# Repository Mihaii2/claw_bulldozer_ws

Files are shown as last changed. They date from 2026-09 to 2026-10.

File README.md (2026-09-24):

# Autonomous Claw Bulldozer ROS 2 Workspace

An autonomous manipulation and earth-moving platform featuring a multi-axis articulating high-torque claw and bucket mechanism, 4WD skid-steer chassis, ESP32 dual-core real-time control, onboard IMU pose tracking, dual camera vision systems, and ROS 2 Jazzy integration.

> 📦 **Hardware Heritage & Lineage Notice:** Core electronics (ESP32 DevKitC, TC1508 H-bridge, GY-BMI160 6-DOF IMU, buck converters) and the baseline micro-ROS architecture were harvested and evolved from the decommissioned [Mihaii2/esp32_flipper_car](https://github.com/Mihaii2/esp32_flipper_car).

<div align="center">
  Autonomous Claw Bulldozer Actuation & Teleoperation Demo<br/>
  <em>Autonomous Claw Bulldozer in action: Synchronized multi-axis lift, bucket articulation, and payload capture.</em>
</div>

<br/>

<div align="center">
  <table>
    <tr>
      <td align="center" width="33%">
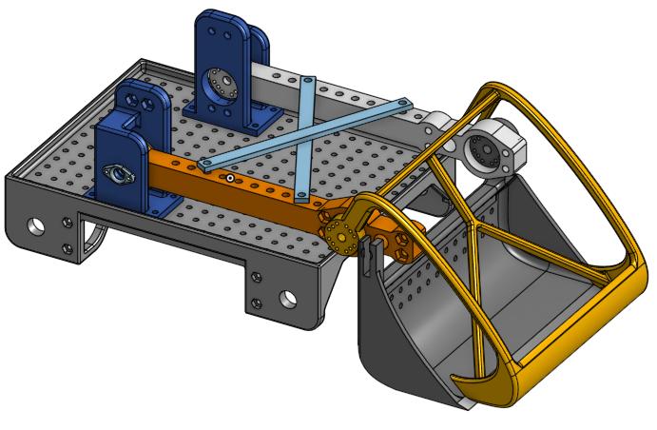
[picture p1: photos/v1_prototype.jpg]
Revision 1: Skinny Skeleton Prototype
        <br/>
        <b>Revision 1: Organic Lattice</b><br/>
        <em>3D round skeleton claw; discarded due to massive support waste and print cost.</em>
      </td>
      <td align="center" width="33%">
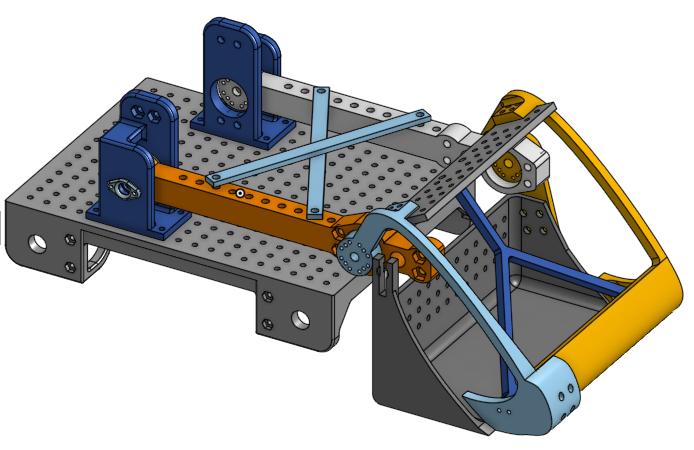
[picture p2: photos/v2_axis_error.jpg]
Revision 2: Off-Axis Pivot
        <br/>
        <b>Revision 2: Split Axis Failure</b><br/>
        <em>Cheaper multi-part claw, but non-concentric pivot axes and horn bolt misalignments failed grip lock.</em>
      </td>
      <td align="center" width="33%">
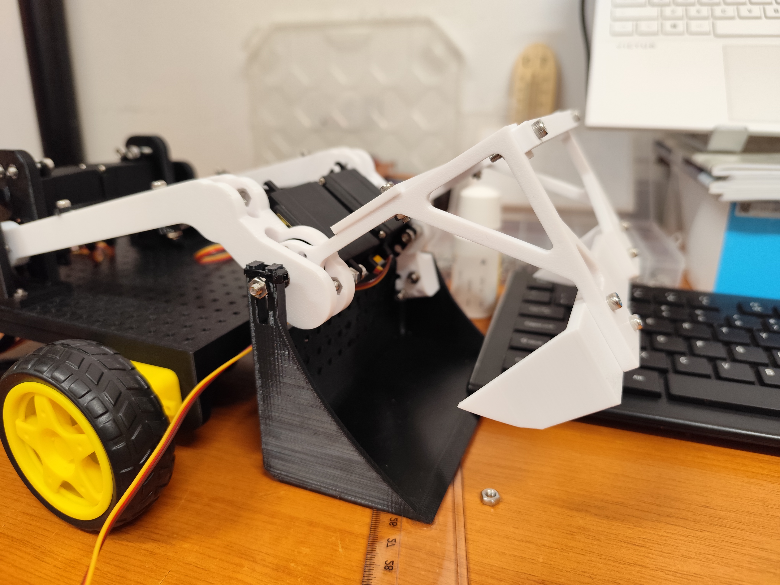
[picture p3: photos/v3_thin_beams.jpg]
Revision 3: Concentric Thin Beams
        <br/>
        <b>Revision 3: Compliant Beams</b><br/>
        <em>Concentric claw/cup axis resolved kinematics, but thin support arms caused excessive structural flex.</em>
      </td>
    </tr>
    <tr>
      <td align="center" width="33%">
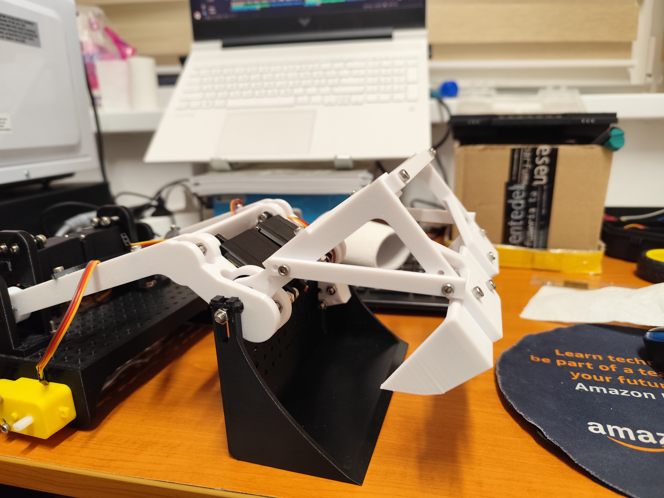
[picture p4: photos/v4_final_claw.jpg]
Revision 4: Rigid Reinforced Claw
        <br/>
        <b>Revision 4: Rigid Production</b><br/>
        <em>Reinforced structural beam geometry; eliminates claw deflection and locks payload into collection cup.</em>
      </td>
      <td align="center" width="33%">
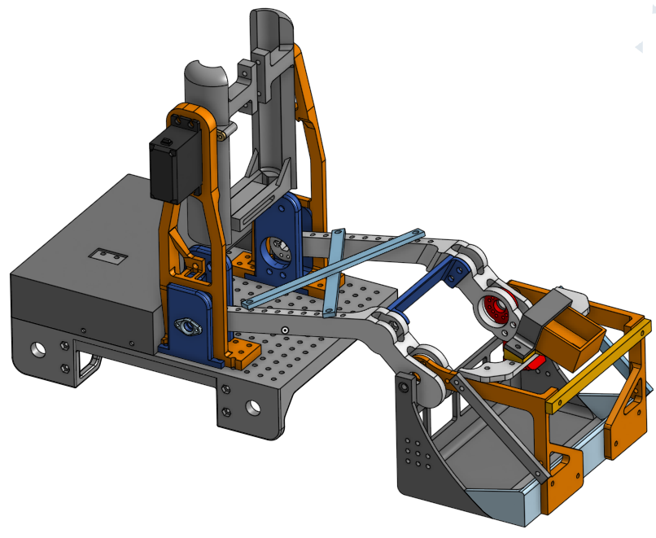
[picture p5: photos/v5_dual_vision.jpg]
Revision 5: Dual Vision & Phone Tilter Rig
        <br/>
        <b>Revision 5: Dual Vision & Enclosure Rig</b><br/>
        <em>Beam-enclosed ESP32-CAM, 5th-servo phone tilter mast, and custom electronics protective cover.</em>
      </td>
      <td align="center" width="33%">
        </td>
    </tr>
  </table>
</div>

> **🛠 Engineering Revision History & CAD Iteration Log:**
> * **v1.0 (Organic Monolithic Claw):** Claw designed as a continuous 3D organic round skeleton. While lightweight on paper, slicer analysis proved it unviable for FDM printing: massive support structures consumed more filament than the part itself, driving print failure rates and material cost excessively high.
> * **v2.0 (Modular Shell & The Pivot Misalignment Post-Mortem):** Redesigned the claw into flat-laying, easily printable structural components, as well as redesigning the chassis goussets to get rid of a lot of waste support plastic. However, rapid CAD prototyping introduced two major mechanical flaws:
>   * **Axial Offset:** The bucket/cup swing axis and the claw rotation axis were placed on disparate coordinate planes rather than a single concentric shaft. The mechanical offset degraded clamping reach, making object acquisition unreliable.
>   * **Horn Geometry Error:** Servo horn mounting hole pitch and bolt clearances were mismeasured, preventing secure mechanical torque transfer without binding.
> * **v3.0 (Concentric Axis & Structural Compliance Investigation):** Redesigned the mounting hub to align the cup and claw along a shared, concentric pivot axis. The mechanical geometry functioned correctly, but the claw extension beams were undersized in thickness. Clamping torque from the MG995 servos flexed the beams outward rather than transferring grip pressure into the target object.
> * **v4.0 (Rigid Structural Reinforcement):** Completely re-engineered the claw support beams with increased cross-sectional area and internal ribbing. Flex is eliminated, permitting high-torque payload capture and retraction directly into the retention cup.
> * **v4.1 (Locomotion Tuning & Track/Wheel Calibration):**
>   * **Wheel Dimensional Scaling:** Replaced oversized 45mm-radius wheel collisions with realistic 20mm-radius (40mm diameter) hubs recessed directly into the chassis axle slots for accurate Gazebo physics and ground clearance.
>   * **Pivot & Scrubbing Firmware Mitigation:** Tuned the differential drive turning profile across all speed gears to supply 100% PWM (255) to the outside wheels and 0% PWM to the inside wheels during turns, breaking lateral static friction without stalling the motors.
>   * **Drivetrain Upgrade Roadmap:** Acquired **all-metal TT 1:90 6V reduction gearboxes** to replace the stock yellow plastic units, delivering substantial low-end torque for heavy earth-moving without risk of gear-tooth shearing.
> * **v5.0 (Perception, High-Current Power & Electronics Shielding — Current Hardware):**
>   * **Initial ESP32-CAM Prototype:** Early tests yielded severe frame-drop bottlenecks, latency, and poor visual fidelity under default configurations.
>   * **Smartphone Mount Pivot:** Designed a dedicated smartphone holder actuated by a 5th MG995 servo on `GPIO 4` to handle primary teleoperation and high-resolution spatial streaming via a mobile device.
>   * **Dual-Camera Convergence & Custom Enclosure:** Subsequent firmware optimizations, clock adjustments, and memory pipeline tuning substantially stabilized ESP32-CAM stream throughput. Attempting to mount the bare board to the pre-existing overhead beam directly above the claw proved mechanically unviable and structurally awkward. Consequently, engineered a custom dedicated 3D-printed plastic enclosure tailored specifically to house the ESP32-CAM and lock rigidly onto the upper beam assembly. The platform now implements a **dual-vision stack**: an actuated smartphone tilter for primary broad-field telemetry and a ruggedized, enclosed ESP32-CAM for direct manipulation monitoring, alongside an upcoming **8×8 Time-of-Flight (ToF)** distance matrix.
>   * **2S2P High-Current Battery Array (Brownout Mitigation):** In the 2-cell configuration, intense multi-joint dynamic actuation (simultaneous 5-servo manipulation alongside aggressive 4WD skid-steer scrubbing) drew more peak current than the pack could sustain. The severe voltage sag triggered brownout resets on the ESP32 logic rail. To resolve this, added two additional 18650 cells wired in parallel (**2S2P topology**). The battery pack maintains nominal **7.4V** while unlocking a massive **20A instantaneous discharge headroom**, ensuring complete electrical stability under full-load operation.
>   * **RF Range Expansion:** Added dedicated 3dBi external dipole antennas to both the main motherboard ESP32 and the secondary ESP32-CAM to prevent telemetry drops and feed degradation across Wi-Fi.
>   * **Electronics Enclosure / Cover:** Designed and printed a custom top-shell protective cover shielding the modular quad-perfboard assembly, buck converters, and wiring harness from earth, debris, and direct mechanical impacts during aggressive digging operations.

---

## 📐 Circuit Schematic

<div align="center">
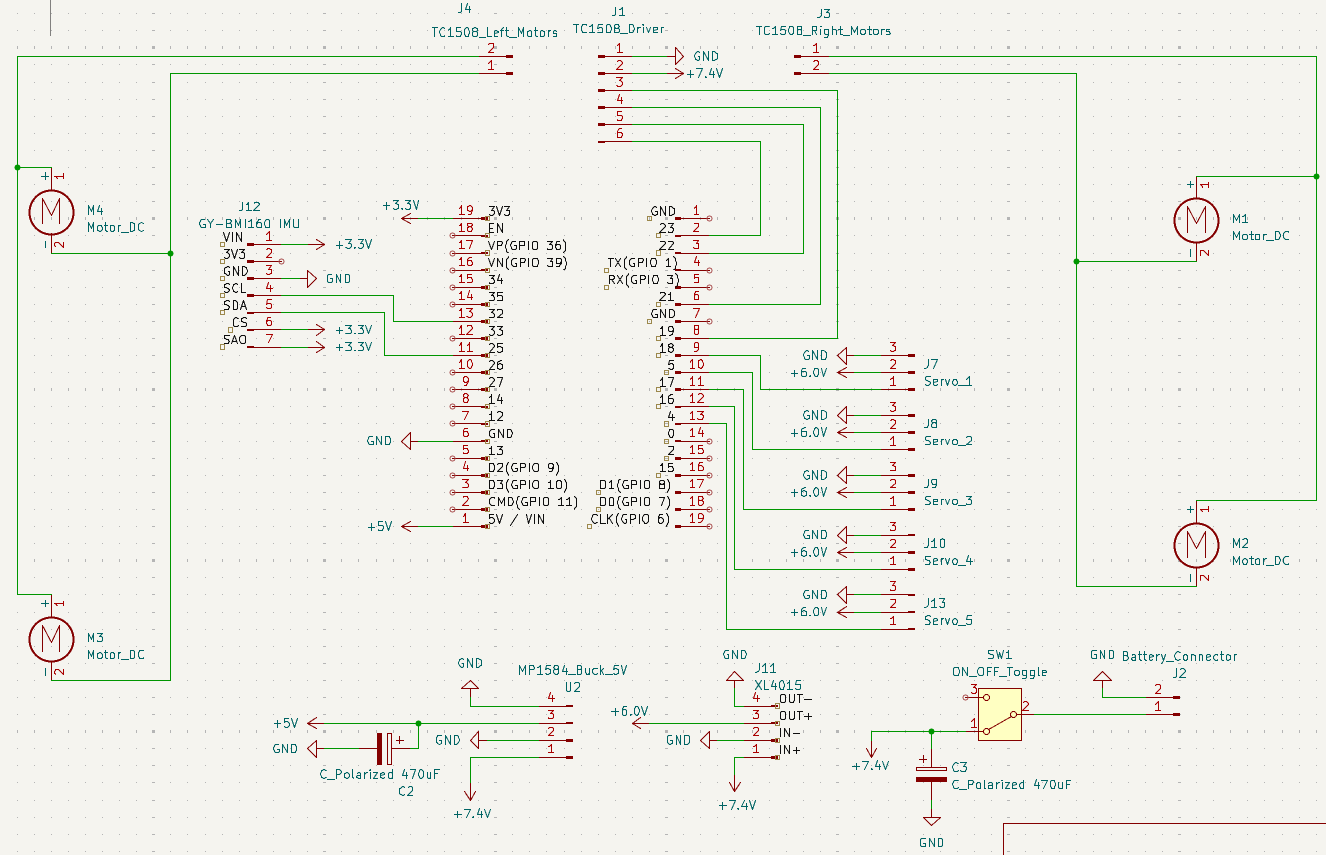
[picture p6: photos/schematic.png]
KiCad Electronics Schematic
  <br/>
  <em>KiCad schematic detailing ESP32 pin mappings, sensor buses, power filtering, and motor/servo actuation stages.</em>
</div>

---

## 🖧 Custom Perfboard Motherboard & Hardware Protection

The primary motherboard is built on a modular composite deck created by joining **four 5cm × 7cm standard perfboards** mechanically using **M2 nuts and bolts**. This bolted multi-board array provides a rigid, vibration-resistant foundation for point-to-point power rails, sensor buses, RF transceivers, and fault isolation:

<div align="center">
  <table>
    <tr>
      <td align="center" width="50%">
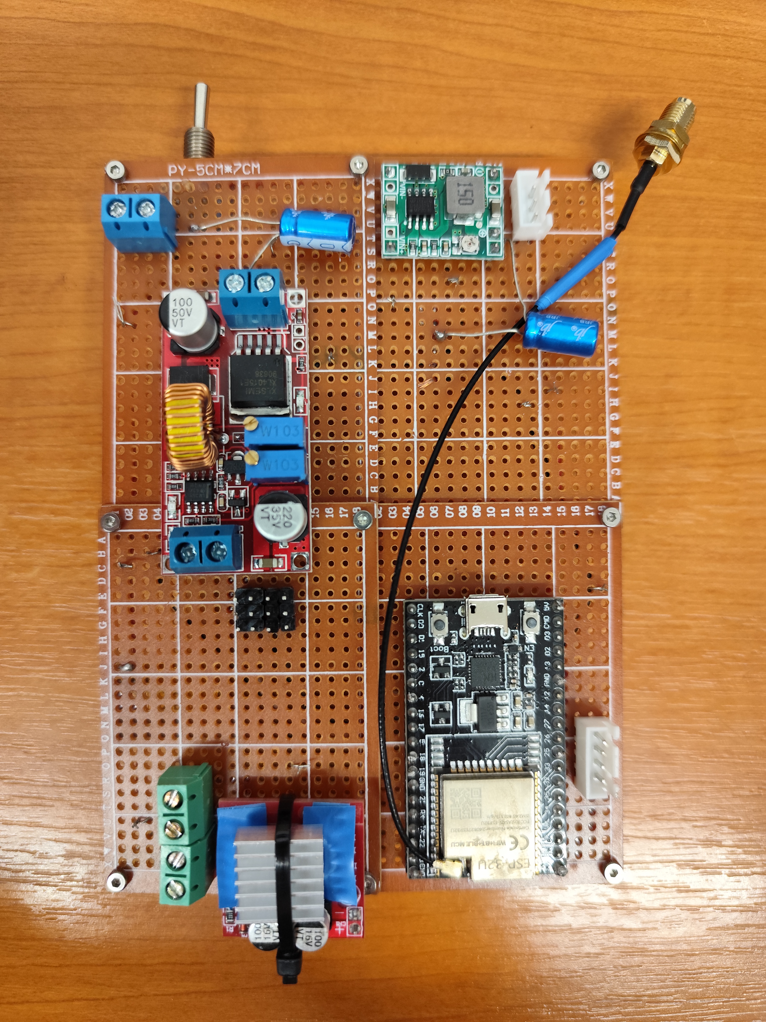
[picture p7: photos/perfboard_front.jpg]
Perfboard Front / Component Placement
        <br/>
        <b>Component Plane (Top Side)</b><br/>
        <em>M2 bolted 4-tile perfboard array with ESP32 DevKit, MP1584EN & XL4015 bucks, heatsinked TC1508, screw terminals, JST-XH headers, 5A fuse, and servo bank.</em>
      </td>
      <td align="center" width="50%">
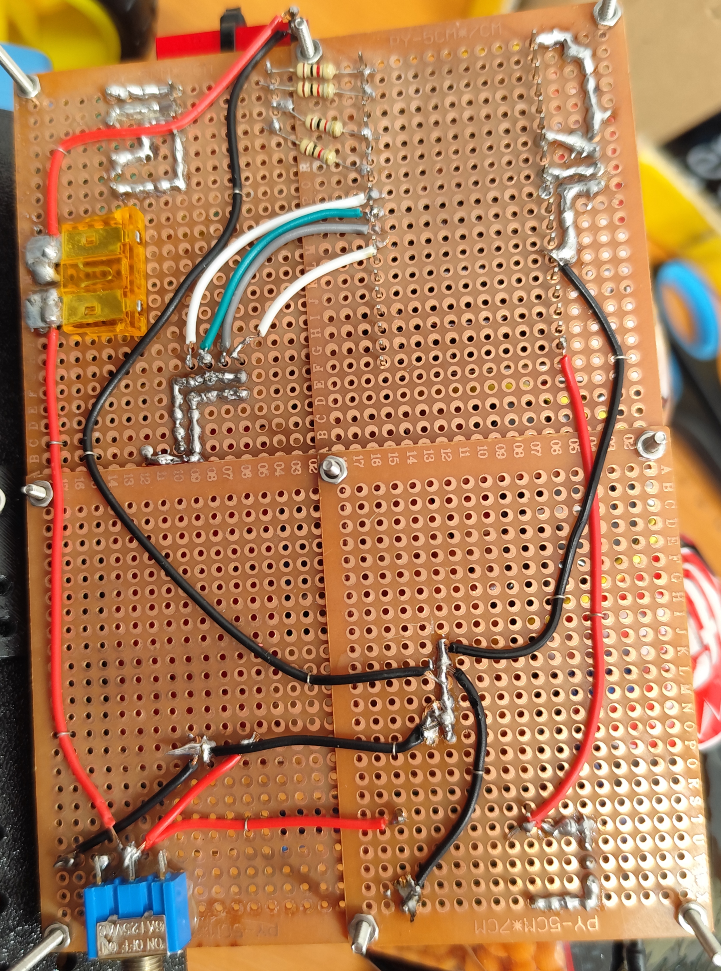
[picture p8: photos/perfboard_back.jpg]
Perfboard Back / Solder Traces
        <br/>
        <b>Trace & Solder Plane (Bottom Side)</b><br/>
        <em>Reinforced copper ground plane, point-to-point interconnect jumpers across the bolted boards, and logic decoupling.</em>
      </td>
    </tr>
  </table>
</div>

### Modular Wiring, Interconnects & Thermal Hardening
* **2S2P High-Current Bus Integration:** 4× 18650 cells wired in a 2-series 2-parallel configuration feed nominal 7.4V with 20A continuous discharge potential into the motherboard, fully eliminating inductive voltage dips and preventing the ESP32 from brownout resetting during heavy maneuvers.
* **Bolted Multi-Board Substrate (M2 Hardware):** Four individual 5cm × 7cm perfboards are mechanically fastened together with M2 nuts and bolts, forming a wide and rigid chassis electronics platform without fragile solder joints bridging structural seams.
* **Modular JST-XH Connectors:**
  * **IMU Interconnect:** Male JST-XH pin headers soldered directly to the perfboard carry the 3.3V logic/I2C lines to a mating female connector harness on the GY-BMI160 sensor.
  * **Auxiliary ESP32-CAM Power:** A dedicated perfboard-soldered male JST-XH connector delivers clean 5.0V logic rail power directly from the MP1584EN buck converter to the camera enclosure harness.
* **Screw Terminal Power & Motor Distribution:**
  * **Battery Bus:** 2× 2-pin PCB screw terminal blocks securely anchor the high-current 7.4V battery input and master return paths without relying on fragile jumper pins.
  * **DC Locomotion:** 4× 2-pin PCB screw terminal blocks connect the left and right drive motor leads directly to the TC1508 motor driver outputs.
* **Active Driver Heat Dissipation:** Under sustained skid-steer scrubbing, the TC1508 motor driver frequently entered internal thermal shutdown. An extruded aluminum heatsink/radiator was thermal-bonded to the IC package, eliminating thermal throttling during stall torque scenarios.
* **MCU Pin Isolation ($4\times 1\,\text{k}\Omega$ Resistors):** Dedicated $1\,\text{k}\Omega$ series current-limiting resistors were installed on every logic trace connecting the ESP32 GPIOs to the TC1508 inputs (`IN1`–`IN4`). If the H-bridge suffers catastrophic shoot-through or internal shorting to the motor supply rail, these resistors prevent high voltage from back-feeding and frying the ESP32 silicon.
* **5A Automotive Blade Fuse:** A standard 5A car blade fuse was soldered directly to the perfboard immediately downstream of the main power switch on the positive line feeding the TC1508 motor rail, isolating full-system shorts and protecting the battery pack from catastrophic damage.

---

## 🧩 Bill of Materials (BOM)

### Current Build (v5.0 Autonomous Dual-Vision Platform)

| Component / Module | Specification / Model | Qty | Description / Role |
|---|---|---|---|
| **Microcontroller** | ESP32 DevKitC V4 (SuooTci / USB) | 1 | Core logic, FreeRTOS tasks, PWM Generation, I2C IMU polling & Micro-ROS bridge |
| **RF Transceivers** | 2.4GHz 3dBi Omni Antennas | 2 | High-gain external antennas on U.FL/SMA pig-tails (1x DevKitC, 1x ESP32-CAM) |
| **IMU Sensor** | Bosch GY-BMI160 (6-DOF) | 1 | 3-axis gyro + 3-axis accelerometer for chassis orientation and terrain profiling |
| **Motor Driver** | TC1508 / MX1508 Dual H-Bridge | 1 | 4-channel DC driver ($2.0\text{V} - 9.6\text{V}$, $1.5\text{A}$ peak/ch) retrofitted with an extruded aluminum radiator |
| **DC Drive Motors** | TT Gearbox DC Motors (3V–9V) | 4 | Chassis locomotion (2x Left, 2x Right in parallel; *all-metal 1:90 6V reduction gearboxes purchased for swap*) |
| **High-Torque Servos** | TowerPro MG995 Metal-Gear | 5 | Actuation: Dual synced arm lift, bucket tilt, claw grip, and phone tilter mechanism |
| **Motherboard Substrate** | 5cm × 7cm Single-Sided Perfboards | 4 | Mechanically bolted together with M2 nuts & bolts into a unified composite deck |
| **Board Assembly Fasteners**| M2 Screws & Hex Nuts | Multi | Mechanical inter-board anchoring linking the four perfboards rigidly |
| **Logic Step-Down** | MP1584EN Buck Converter | 1 | Regulates 7.4V battery pack down to stable 5.0V for ESP32 VIN & ESP32-CAM |
| **Servo Step-Down** | XL4015 High-Current Buck Converter | 1 | High-capacity DC-DC step down (7.4V to 6.0V, $\ge 5\text{A}$) dedicated to MG995 servo array |
| **Logic Isolation** | $1\,\text{k}\Omega$ Resistors (Through-Hole) | 4 | Inline current-limiting protection on MCU-to-TC1508 logic control lines |
| **Circuit Fuse** | Standard Automotive Blade Fuse (5A) | 1 | Car blade fuse soldered directly to perfboard on the TC1508 7.4V battery input rail |
| **Signal Interconnects** | JST-XH 2.54mm Headers & Plugs | 2 | Motherboard male headers + wire plugs for modular IMU bus and ESP32-CAM 5V supply |
| **Power Interconnects** | 2-Pin Screw Terminal Blocks (5.08mm) | 6 | High-current connections (2x Battery bus input, 4x TT DC Motor outputs) |
| **Power Decoupling Caps**| $470\,\mu\text{F}$ Electrolytic ($\ge 16\text{V}$) | 2 | Inductive spike and brownout protection (1x on 7.4V battery rail, 1x on 5.0V logic rail) |
| **Main Battery Pack** | 18650 Li-ion Cells (2S2P / 7.4V Nominal) | 4 | High-discharge power source delivering up to 20A continuous at 7.4V to eliminate MCU resets |
| **Main Power Switch** | Mini 3-Pin SPDT Toggle Switch | 1 | Master battery circuit cutoff switch |
| **Electronics Shell** | 3D-Printed Top Bay Enclosure | 1 | Protective cover shielding motherboard, buck regulators, and wiring harness |
| **Secondary Vision** | ESP32-CAM in Custom 3D Enclosure | 1 | Close-proximity claw inspection; housed in a custom enclosure overcoming beam-mounting limits |
| **Primary Vision** | Articulated Smartphone Tilter Mount | 1 | Dynamic tilting mobile phone rig actuated via 5th MG995 servo on `GPIO 4` |
| **Depth Sensor (Roadmap)** | 8x8 Multizone ToF Matrix Sensor | 1 | Surface profiling and short-range claw docking validation |

---

### Legacy Hardware Donor: [Mihaii2/esp32_flipper_car](https://github.com/Mihaii2/esp32_flipper_car)

| Component / Module | Specification / Model | Qty | Status in Current Project |
|---|---|---|---|
| **Microcontroller** | ESP32 DevKitC V4 | 1 | **Migrated:** Re-flashed with manipulator kinematics and 5-channel servo control. |
| **Motor Driver** | TC1508 Dual H-Bridge | 1 | **Migrated:** Retained with aluminum heatsink and resistor isolation for chassis drive. |
| **DC Motors** | TT Gearbox DC Motors (3V–9V) | 4 | **Migrated:** Reused for chassis drive train (*all-metal 1:90 6V units already purchased for swap*). |
| **IMU Sensor** | Bosch GY-BMI160 (6-DOF) | 1 | **Migrated:** Shifted from balance control to kinematic leveling and terrain detection. |
| **Filter Capacitors** | $470\,\mu\text{F}$ Electrolytic ($\ge 16\text{V}$) | 2 | **Migrated:** Retained for dual-rail bus filtering. |
| **Buck Converter** | MP1584EN | 1 | **Migrated:** Retained as dedicated logic rail regulator. |
| **Tilt Switch** | SW-520D Ball Switch | 1 | **Deprecated:** Retired in favor of 6-DOF IMU telemetry. |
| **Dynamic Inversion Logic**| Auto-Flip Firmware Controller | — | **Deprecated:** Replaced by kinematic trajectory control for arm and bucket. |

---

## 🛠 Features
- **Articulated High-Torque Clamping:** 4× MG995 servos providing dual-arm lifting, cup tilting, and active payload grabbing.
- **Dynamic Perception Mast:** 5th MG995 servo driving an adjustable-pitch smartphone cradle alongside a dedicated, encased ESP32-CAM for dual-angle perception.
- **2S2P Anti-Brownout Power Bus:** 4× 18650 cell array supplying 20A continuous headroom at 7.4V, resolving previous ESP32 logic resets during high-strain claw and track maneuvers.
- **Reinforced M2-Bolted Backbone:** 4-piece perfboard array rigidly locked with M2 hardware, integrated with screw terminals and keyed JST-XH wiring harnesses for modular serviceability.
- **High-Gain RF Connectivity:** Dual 3dBi external antennas eliminating packet drop on high-bandwidth ROS 2 telemetry and camera streams.
- **Debris & Impact Shielding:** Custom 3D-printed electronics housing protecting motherboards, buck converters, and connections against soil fallout.
- **Fail-Safe Electrical Design:** Perfboard-soldered 5A car blade fuse, $4\times 1\,\text{k}\Omega$ MCU gate isolation resistors, and an aluminum thermal radiator preventing driver burnout.
- **Dual-Rail Isolated Power Distribution:** High-current XL4015 buck converter isolates heavy servo inductive back-EMF from the ESP32 logic rail.
- **Calibrated Skid-Steer Kinematics:** Asymmetrical 100/0 PWM steering regime breaks track scrubbing, supplemented by 20mm scale-matched wheel collisions.
- **Concentric Axis Kinematics:** Revision 4 unibody geometry maintains zero rotational shear between retention cup and claw swing arcs.
- **Native Micro-ROS Integration:** ESP32 communicates deterministic low-latency telemetry and joint states natively to ROS 2 Jazzy over XRCE-DDS.
- **Dual-Core FreeRTOS Execution:** Decoupled architecture isolating high-speed I2C sensor/PWM routines from network communication.

---

## 🔌 Hardware Architecture & Power Routing

```mermaid
graph TD
    Batt["4x 18650 Battery Array<br/>(2S2P Topology, 7.4V Nominal, 20A Headroom)"] --> Switch["3-Pin Toggle Switch"]
    Switch --> ScrewBatt["2x Screw Terminals<br/>(Main 7.4V Bus)"]
    
    subgraph PowerDistribution["Modular Deck (4x 5x7cm Perfboards Bolted with M2 Hardware)"]
        ScrewBatt --> Cap1["470uF Bulk Filter"]
        Cap1 --> XL4015["XL4015 Buck Converter<br/>(Steps down to 6.0V, 5A Peak)"]
        Cap1 --> MP1584["MP1584EN Buck Converter<br/>(Steps down to 5.0V)"]
        ScrewBatt --> Fuse["5A Car Blade Fuse<br/>(Soldered to Perfboard)"]
        MP1584 --> Cap2["470uF Logic Filter"]
        MP1584 --> JST_Cam["JST-XH 5V Power Connector"]
    end

    subgraph Actuators["High-Current Actuation"]
        XL4015 -->|"6.0V Rail"| Servos["5x MG995 Servos<br/>(Arm Sync, Cup, Claw, Phone Tilter)"]
        Fuse -->|"Protected 7.4V Rail"| TC1508["TC1508 H-Bridge<br/>(+ Radiator / Heatsink)"]
        TC1508 --> ScrewMotors["4x Screw Terminals"]
        ScrewMotors --> TT_Motors["4x TT Motors<br/>(Skid-Steer Locomotion)"]
    end

    subgraph LogicAndSensors["Logic & Processing Plane (Cover Enclosure)"]
        Cap2 -->|"5.0V VIN"| ESP32["ESP32 DevKitC V4<br/>(+ 3dBi Antenna)"]
        ESP32 -->|"JST-XH Harness (3.3V/I2C)"| BMI160["Bosch GY-BMI160 (6-DOF IMU)"]
        ESP32 -->|"PWM Control (LEDC)"| Servos
        ESP32 -->|"4x 1k Series Resistors"| TC1508
        ESP32 -.->|"Future Expansion"| ToF["8x8 ToF Matrix Sensor"]
        JST_Cam --> ESP32Cam["ESP32-CAM in Custom Enclosure<br/>(+ 3dBi Antenna)"]
        ESP32Cam -.->|"WLAN Stream"| ROS2["ROS 2 Ecosystem"]
        Phone["Smartphone (Tilter Mount)"] -.->|"WebRTC / RTSP"| ROS2
    end
```

---

## ⚡ Hardware Pinout (ESP32)

Unified GPIO allocation across motor drive stages, servo PWM channels, and sensor buses:

| Subsystem | Component Pin | ESP32 GPIO / Rail | Peripheral / Channel | Function / Calibration Limits |
|---|---|---|---|---|
| **DC Drive (TC1508)** | `IN1` | `GPIO 23` | GPIO Output via $1\,\text{k}\Omega$ Resistor | Right Track Motor (Direction A) |
| **DC Drive (TC1508)** | `IN2` | `GPIO 22` | GPIO Output via $1\,\text{k}\Omega$ Resistor | Right Track Motor (Direction B) |
| **DC Drive (TC1508)** | `IN3` | `GPIO 21` | GPIO Output via $1\,\text{k}\Omega$ Resistor | Left Track Motor (Direction A) |
| **DC Drive (TC1508)** | `IN4` | `GPIO 19` | GPIO Output via $1\,\text{k}\Omega$ Resistor | Left Track Motor (Direction B) |
| **Servos (MG995)** | Arm Base Left | `GPIO 18` | `LEDC_CHANNEL_0` | `132.0°` (Down / 0%) to `44.0°` (Up / 100%) |
| **Servos (MG995)** | Arm Base Right | `GPIO 5` | `LEDC_CHANNEL_1` | `40.0°` (Down / 0%) to `124.0°` (Up / 100%) *(Mirrored sync)* |
| **Servos (MG995)** | Cup / Wrist Tilt | `GPIO 17` | `LEDC_CHANNEL_2` | Independent Pitch Mechanism |
| **Servos (MG995)** | Claw Gripper | `GPIO 16` | `LEDC_CHANNEL_3` | Independent Grip / Release Mechanism |
| **Servos (MG995)** | Phone Tilter | `GPIO 4` | `LEDC_CHANNEL_4` | Actuated Camera / Phone Pitch Control |
| **IMU (BMI160)** | `SCL` | `GPIO 32` | `I2C_NUM_0` SCL via JST-XH | Hardware I2C Clock Line |
| **IMU (BMI160)** | `SDA` | `GPIO 25` | `I2C_NUM_0` SDA via JST-XH | Hardware I2C Data Line |
| **IMU (BMI160)** | `CS` / `SA0` | `3.3V Rail` | Logic High via JST-XH | Forces I2C Mode / Sets Address to `0x69` |

> *Note: All MG995 servos utilize `LEDC_TIMER_0` configured for 50 Hz PWM with 14-bit resolution.*

---

## 🚀 Getting Started

### Prerequisites
- Ubuntu 22.04 / 24.04
- ROS 2 (Jazzy / Humble)
- ESP-IDF v5.2+
- Docker (for micro-ROS agent)

```bash
### Build & Run
# Clone and enter workspace
cd ~/ROS_projects/claw_bulldozer_ws

# Build the ROS 2 packages
colcon build --symlink-install

# Source the overlay
source install/setup.bash

# Run main bringup script
./run.sh

# Source ESP-IDF environment
. $HOME/esp/esp-idf/export.sh

# Navigate to firmware project
cd ~/ROS_projects/claw_bulldozer_ws/firmware/flipper_firmware

# Build, flash to ESP32, and launch UART monitor
idf.py build flash monitor

# Start micro-ROS Agent (in separate terminal)
docker run -it --rm --net=host microros/micro-ros-agent:jazzy udp4 --port 8888
```

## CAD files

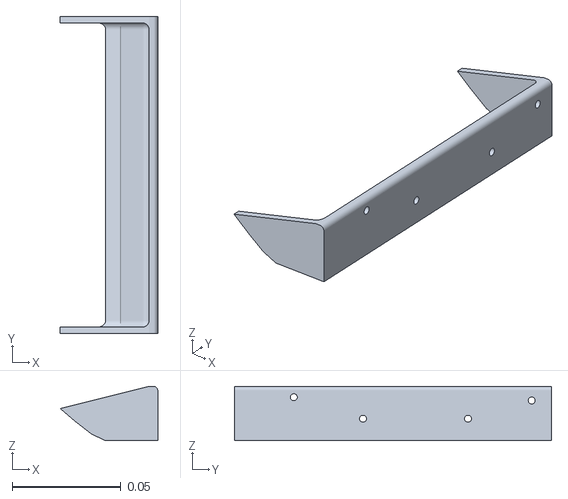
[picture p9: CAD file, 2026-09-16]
src/bulldozer/meshes/Part Studio 1 - 15_Claw_Grabber.stl
0.0449 x 0.146 x 0.025

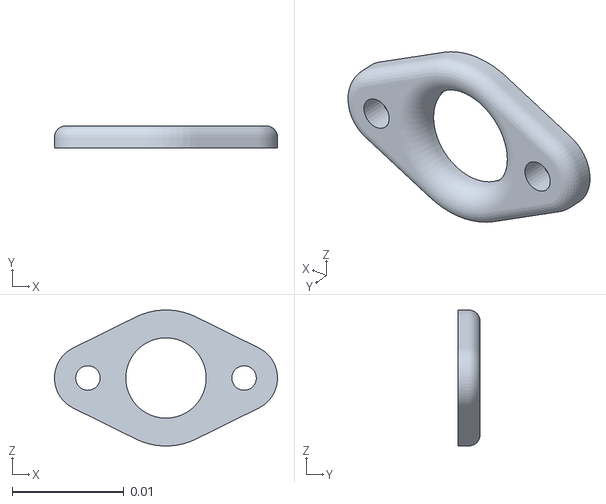
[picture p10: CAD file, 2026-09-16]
src/bulldozer/meshes/Part Studio 1 - 06_Bearing_Flange_1.stl
0.02 x 0.002 x 0.0122

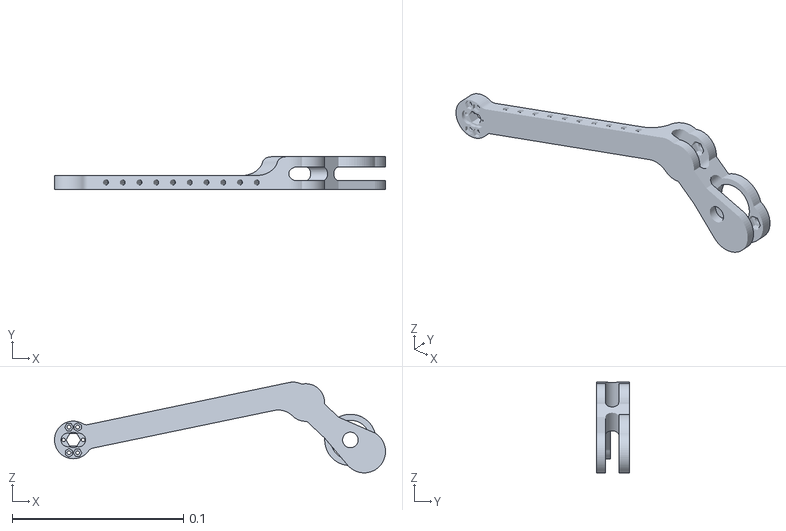
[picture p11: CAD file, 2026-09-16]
src/bulldozer/meshes/Part Studio 1 - 10_Right_Arm.stl
0.193 x 0.019 x 0.053

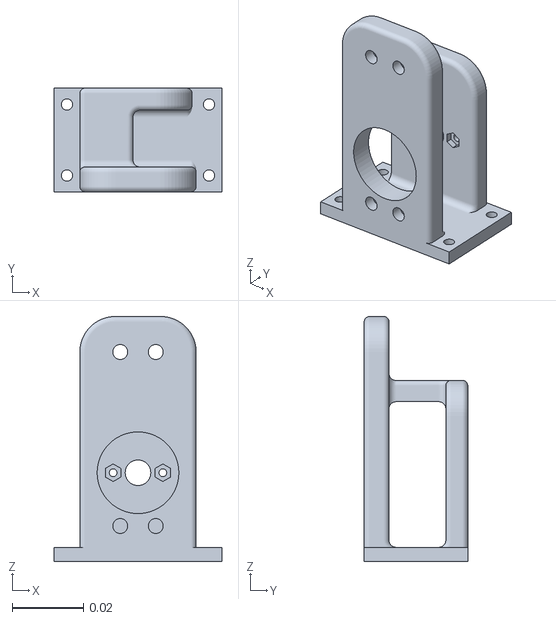
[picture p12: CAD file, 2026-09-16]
src/bulldozer/meshes/Part Studio 1 - 03_Arm_Base_Mount_Left.stl
0.0472 x 0.0292 x 0.069

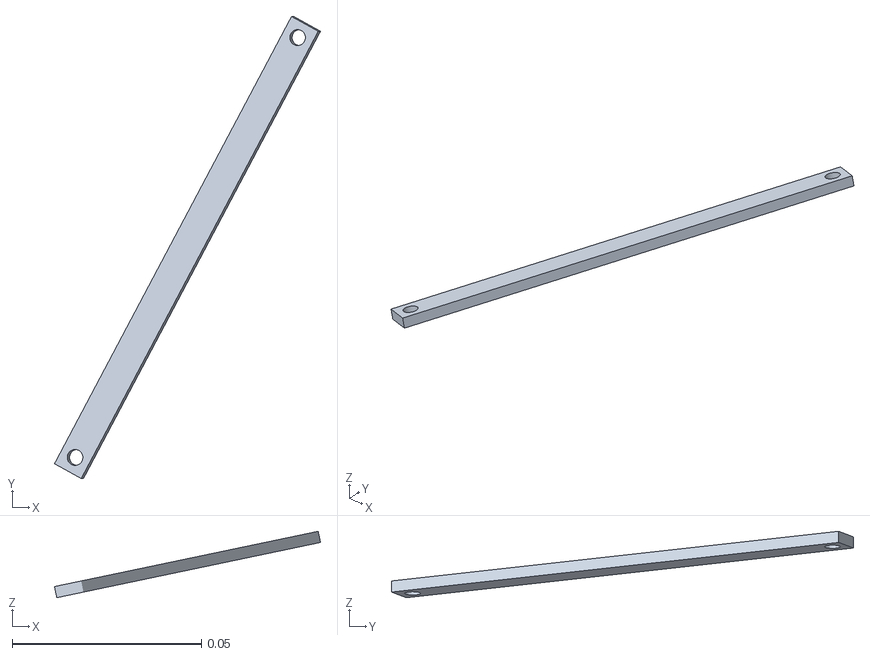
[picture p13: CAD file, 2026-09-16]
src/bulldozer/meshes/Part Studio 1 - 11_Arms_Support_Beam_2.stl
0.0702 x 0.122 x 0.0175

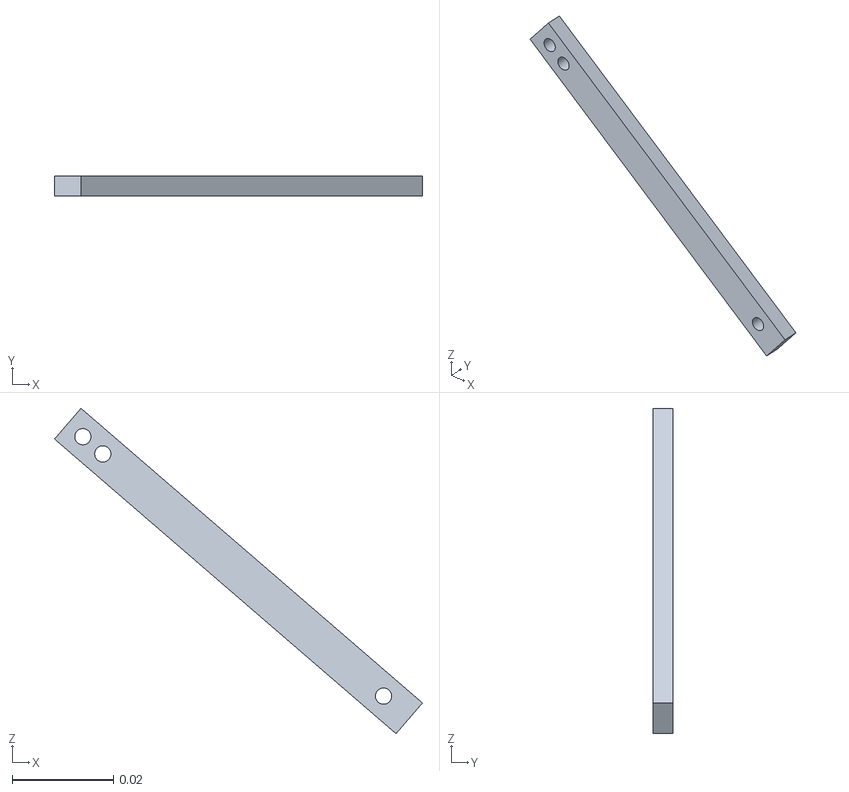
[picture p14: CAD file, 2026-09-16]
src/bulldozer/meshes/Part Studio 1 - 16_Right_Claw_Beam.stl
0.0726 x 0.004 x 0.0642

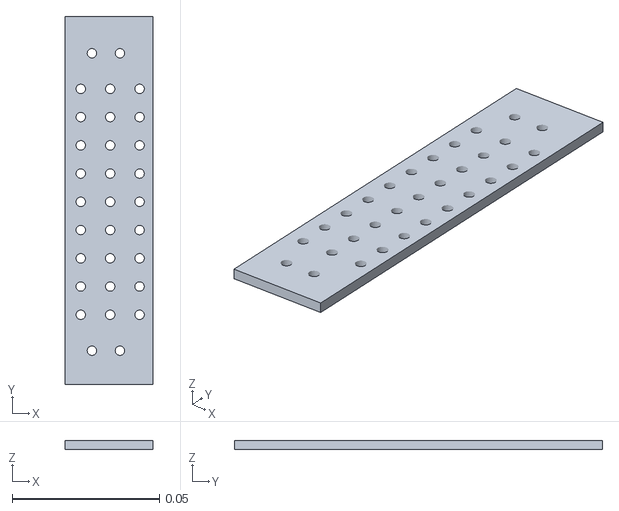
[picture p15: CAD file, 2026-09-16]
src/bulldozer/meshes/Part Studio 1 - 15_Cam_Holder.stl
0.03 x 0.125 x 0.003

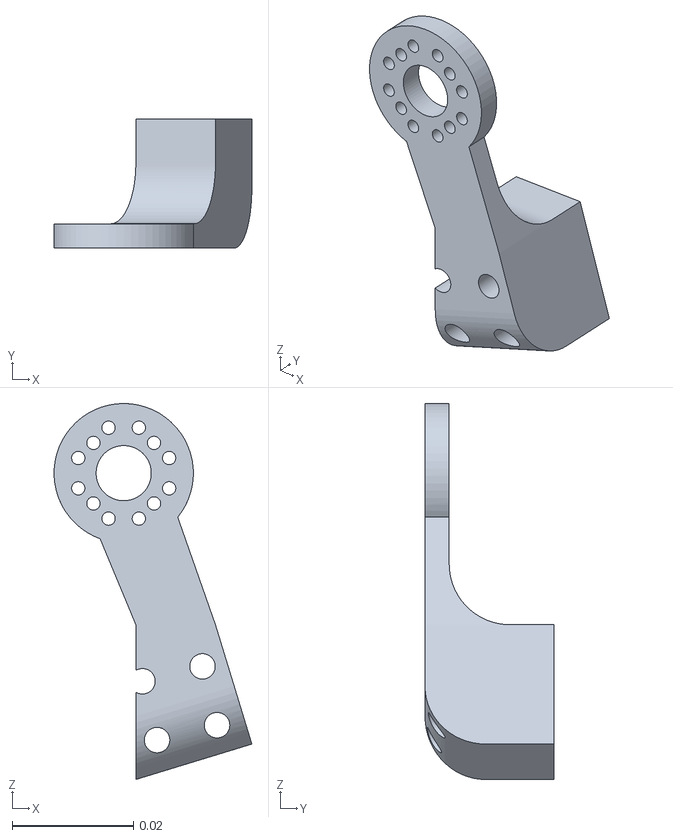
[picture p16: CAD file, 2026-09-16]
src/bulldozer/meshes/Part Studio 1 - 09_Cup_Arm_Connector.stl
0.0326 x 0.0213 x 0.0621

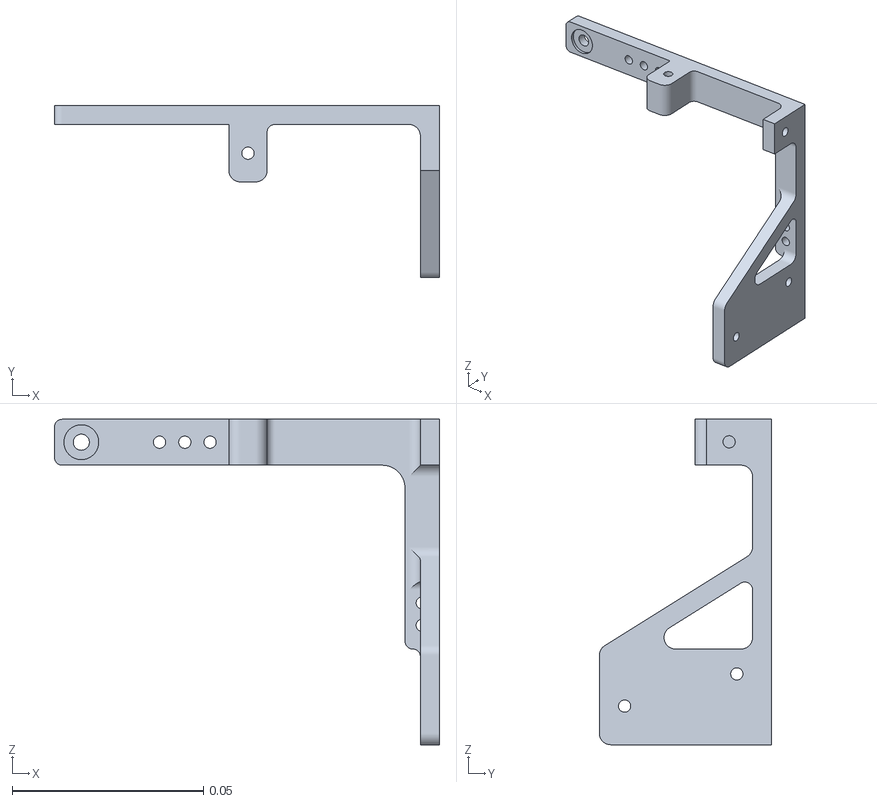
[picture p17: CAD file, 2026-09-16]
src/bulldozer/meshes/Part Studio 1 - 14_Left_Claw_Beam.stl
0.101 x 0.045 x 0.085

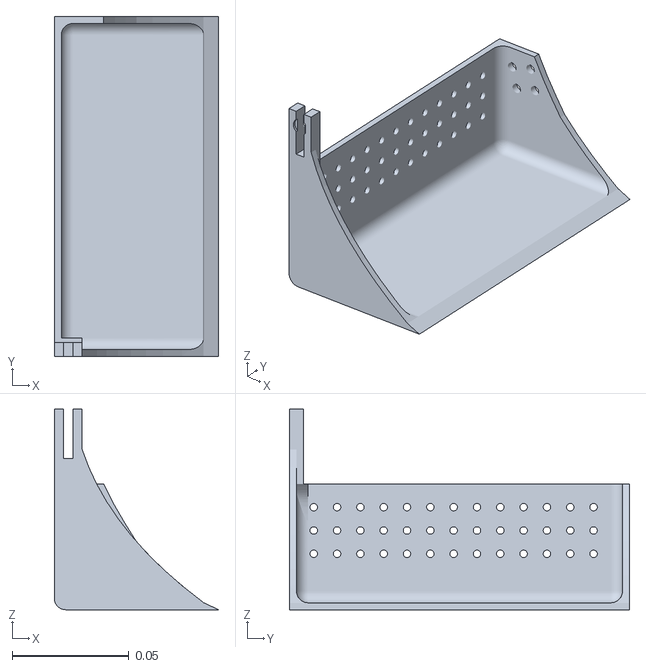
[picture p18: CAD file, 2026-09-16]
src/bulldozer/meshes/Part Studio 1 - 08_Cup.stl
0.0705 x 0.146 x 0.086

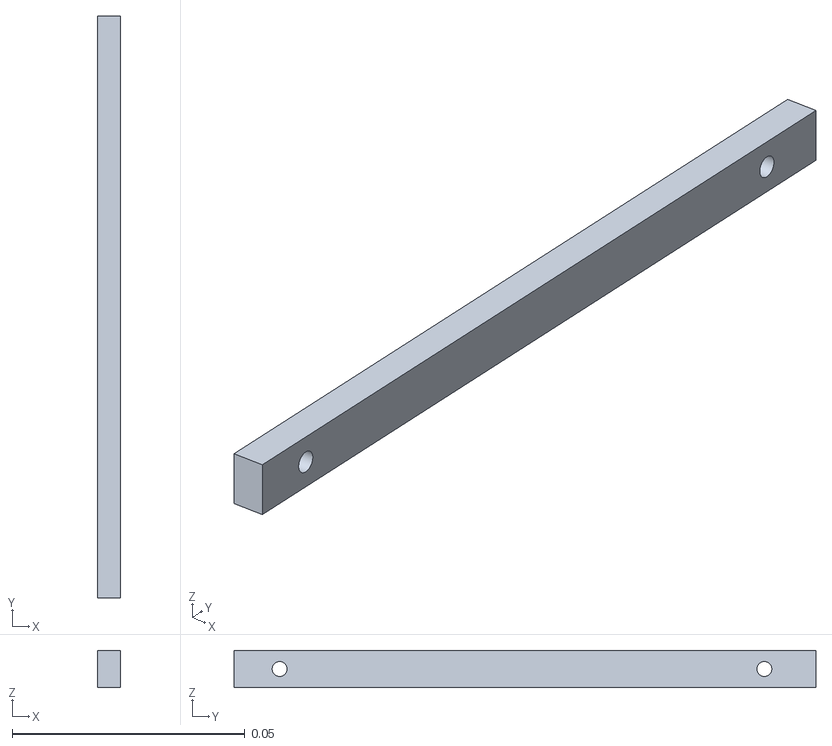
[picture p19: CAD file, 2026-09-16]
src/bulldozer/meshes/Part Studio 1 - 19_Claw_Front_Beam.stl
0.005 x 0.125 x 0.008

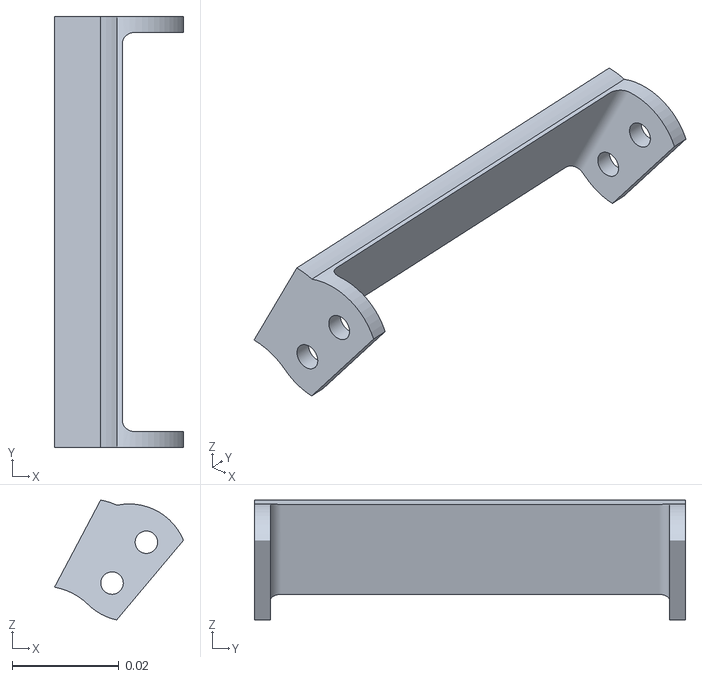
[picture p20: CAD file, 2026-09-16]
src/bulldozer/meshes/Part Studio 1 - 18_Arms_Vertical_Support.stl
0.0242 x 0.0808 x 0.0225

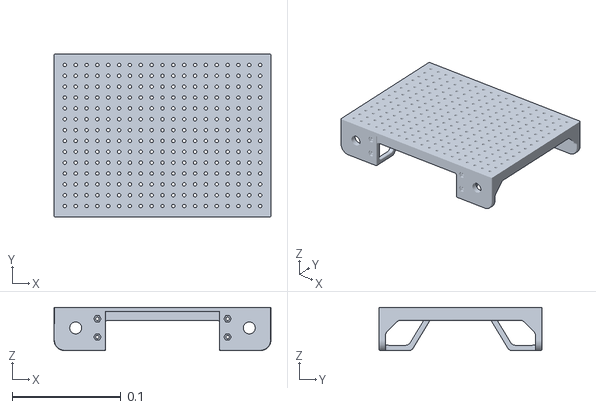
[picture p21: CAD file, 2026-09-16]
src/bulldozer/meshes/Part Studio 1 - 02_Chassis_Base.stl
0.2 x 0.15 x 0.04

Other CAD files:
src/bulldozer/meshes/Part Studio 1 - 04_Arm_Base_Mount_Right.stl
src/bulldozer/meshes/Part Studio 1 - 10_Arms_Support_Beam_1.stl
src/bulldozer/meshes/Part Studio 1 - 06_Bearing_Flange_2.stl
src/bulldozer/meshes/Part Studio 1 - 05_Lift_Left_Arm.stl
src/bulldozer/meshes/Part Studio 1 - 17_Left_Claw_Beam.stl
src/bulldozer/meshes/Part Studio 1 - 07_Left_Arm_Nut_Flange.stl
src/bulldozer/meshes/Part Studio 1 - 12_Right_Arm_Nut_Flange.stl
src/bulldozer/meshes/Part Studio 1 - 13_Right_Claw_Beam.stl

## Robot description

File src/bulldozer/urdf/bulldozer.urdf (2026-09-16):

<?xml version="1.0"?>
<robot name="bulldozer">

  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
  <link name="base_link">
    <inertial>
      <mass value="0.75"/>
      <origin xyz="0 0 0" rpy="0 0 0"/>
      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
    </inertial>

    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
  </link>

  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
  <link name="arm_link">
    <inertial>
      <mass value="0.25"/>
      <origin xyz="0 0 0" rpy="0 0 0"/>
      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
    </inertial>

    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
  </link>

  <joint name="arm_joint" type="revolute">
    <parent link="base_link"/>
    <child link="arm_link"/>
    <origin xyz="0 0 0" rpy="0 0 0"/>
    <axis xyz="0 1 0"/>
    <limit lower="-0.80" upper="0.80" effort="3.0" velocity="2.0"/>
  </joint>

  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
  <link name="cup_link">
    <inertial>
      <mass value="0.12"/>
      <origin xyz="0 0 0" rpy="0 0 0"/>
      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
    </inertial>

    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
  </link>

  <joint name="cup_joint" type="revolute">
    <parent link="arm_link"/>
    <child link="cup_link"/>
    <origin xyz="0 0 0" rpy="0 0 0"/>
    <axis xyz="0 1 0"/>
    <limit lower="-1.22" upper="1.22" effort="2.0" velocity="2.0"/>
  </joint>

  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
  <link name="claw_link">
    <inertial>
      <mass value="0.10"/>
      <origin xyz="0 0 0" rpy="0 0 0"/>
      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
    </inertial>

    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
  </link>

  <joint name="claw_joint" type="revolute">
    <parent link="cup_link"/>
    <child link="claw_link"/>
    <origin xyz="0 0 0" rpy="0 0 0"/>
    <axis xyz="0 0 1"/>
    <limit lower="-1.22" upper="1.22" effort="2.0" velocity="2.0"/>
  </joint>

  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
  <link name="front_left_wheel">
    <inertial>
      <mass value="0.03"/>
      <origin xyz="0 0 0" rpy="1.5708 0 0"/>
      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
    </inertial>
    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
  </link>
  <joint name="front_left_joint" type="continuous">
    <parent link="base_link"/>
    <child link="front_left_wheel"/>
    <origin xyz="0.040 0.048 -0.012" rpy="0 0 0"/>
    <axis xyz="0 1 0"/>
  </joint>

  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
  <link name="rear_left_wheel">
    <inertial>
      <mass value="0.03"/>
      <origin xyz="0 0 0" rpy="1.5708 0 0"/>
      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
    </inertial>
    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
  </link>
  <joint name="rear_left_joint" type="continuous">
    <parent link="base_link"/>
    <child link="rear_left_wheel"/>
    <origin xyz="-0.040 0.048 -0.012" rpy="0 0 0"/>
    <axis xyz="0 1 0"/>
  </joint>

  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
  <link name="front_right_wheel">
    <inertial>
      <mass value="0.03"/>
      <origin xyz="0 0 0" rpy="1.5708 0 0"/>
      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
    </inertial>
    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
  </link>
  <joint name="front_right_joint" type="continuous">
    <parent link="base_link"/>
    <child link="front_right_wheel"/>
    <origin xyz="0.040 -0.048 -0.012" rpy="0 0 0"/>
    <axis xyz="0 1 0"/>
  </joint>

  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
  <link name="rear_right_wheel">
    <inertial>
      <mass value="0.03"/>
      <origin xyz="0 0 0" rpy="1.5708 0 0"/>
      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
    </inertial>
    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
  </link>
  <joint name="rear_right_joint" type="continuous">
    <parent link="base_link"/>
    <child link="rear_right_wheel"/>
    <origin xyz="-0.040 -0.048 -0.012" rpy="0 0 0"/>
    <axis xyz="0 1 0"/>
  </joint>

  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

</robot>

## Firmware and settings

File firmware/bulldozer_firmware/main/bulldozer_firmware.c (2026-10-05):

#include <stdio.h>
#include <string.h>
#include <math.h>
#include <stdlib.h>
#include <unistd.h>
#include <sys/socket.h>
#include <netinet/in.h>
#include <arpa/inet.h>

#include "freertos/FreeRTOS.h"
#include "freertos/task.h"
#include "freertos/event_groups.h"
#include "esp_system.h"
#include "esp_wifi.h"
#include "esp_event.h"
#include "esp_log.h"
#include "nvs_flash.h"
#include "esp_timer.h"
#include "driver/ledc.h"
#include "driver/gpio.h"

#include <rcl/rcl.h>
#include <rcl/error_handling.h>
#include <rclc/rclc.h>
#include <rclc/executor.h>
#include <rmw_microros/rmw_microros.h>

#include <std_msgs/msg/string.h>

#define TAG "BULLDOZER_MICROROS"

// ==========================================
// === Router & micro-ROS Settings ==========
// ==========================================
#define TARGET_SSID         "Project"
#define TARGET_PASS         "formula1"
#define AGENT_IP            "10.42.0.1"
#define AGENT_PORT          "8888"

// ==========================================
// === Hardware Pinout Configuration ========
// ==========================================
#define MOTOR_L_IN1         GPIO_NUM_23
#define MOTOR_L_IN2         GPIO_NUM_22
#define MOTOR_R_IN3         GPIO_NUM_21
#define MOTOR_R_IN4         GPIO_NUM_19

#define CAM_SERVO_PIN       GPIO_NUM_4
#define ARM_L_SERVO_PIN     GPIO_NUM_18
#define ARM_R_SERVO_PIN     GPIO_NUM_5
#define CUP_SERVO_PIN       GPIO_NUM_17
#define CLAW_SERVO_PIN      GPIO_NUM_16

#define CH_SERVO_CAM        LEDC_CHANNEL_0
#define CH_SERVO_ARM_L      LEDC_CHANNEL_1
#define CH_SERVO_ARM_R      LEDC_CHANNEL_2
#define CH_SERVO_CUP        LEDC_CHANNEL_3
#define CH_SERVO_CLAW       LEDC_CHANNEL_4

#define CH_MOT_L_IN1        LEDC_CHANNEL_5
#define CH_MOT_L_IN2        LEDC_CHANNEL_6
#define CH_MOT_R_IN3        LEDC_CHANNEL_7

#define SERVO_TIMER         LEDC_TIMER_0
#define MOTOR_TIMER         LEDC_TIMER_1

#define SERVO_FREQ_HZ       50
#define SERVO_DUTY_RES      LEDC_TIMER_14_BIT

#define MOTOR_FREQ_HZ       1000
#define MOTOR_DUTY_RES      LEDC_TIMER_8_BIT
#define MOTOR_MAX_DUTY      255

// 2-Gear Configuration
#define DUTY_65_PCT         166
#define DUTY_100_PCT        255
static int current_drive_duty = DUTY_100_PCT;

#define DRIVE_TIMEOUT_US    160000 
static int64_t last_drive_cmd_time = 0;
static bool motors_active = false;

typedef struct {
    float arm_l_down;
    float arm_l_up;
    float arm_r_down;
    float arm_r_up;
} arm_calib_t;

static arm_calib_t arm_cal = {
    .arm_l_down = 138.0f,
    .arm_l_up   = 42.0f,
    .arm_r_down = 34.0f,
    .arm_r_up   = 122.0f
};

typedef struct {
    float target;
    float current;
    float max_step;
} servo_channel_state_t;

// Speed adjusted: Arms @ 75% (7.5f), Cup & Claw matching @ 10.0f
// Cam servo initialized explicitly to 0.0f
static servo_channel_state_t servo_cam   = { .target = 0.0f,   .current = 0.0f,   .max_step = 32.0f };
static servo_channel_state_t servo_arm_l = { .target = 99.6f,  .current = 99.6f,  .max_step = 7.5f };
static servo_channel_state_t servo_arm_r = { .target = 69.2f,  .current = 69.2f,  .max_step = 7.5f };
static servo_channel_state_t servo_cup   = { .target = 90.0f,  .current = 90.0f,  .max_step = 10.0f };
static servo_channel_state_t servo_claw  = { .target = 90.0f,  .current = 90.0f,  .max_step = 10.0f };

// User Memorized Intentions
static float intent_cam          = 0.0f;
static float intent_cup          = 90.0f;
static float intent_claw         = 90.0f;
static float current_arm_percent = 40.0f;

// Delay gate initialized to 1 so 0 deg is immediately active on boot
static int64_t cam_clearance_ready_time = 1;

static portMUX_TYPE angle_mux = portMUX_INITIALIZER_UNLOCKED;

static EventGroupHandle_t wifi_event_group;
#define WIFI_CONNECTED_BIT BIT0

static inline uint32_t angle_to_ticks(float angle) {
    if (angle < 0.0f)   angle = 0.0f;
    if (angle > 180.0f) angle = 180.0f;
    float pulse_us = 500.0f + (angle / 180.0f) * 2000.0f;
    return (uint32_t)(pulse_us / 1.2207f);
}

static void apply_raw_servo(ledc_channel_t ch, float angle) {
    ledc_set_duty(LEDC_LOW_SPEED_MODE, ch, angle_to_ticks(angle));
    ledc_update_duty(LEDC_LOW_SPEED_MODE, ch);
}

static void set_motor_speeds(int left_pwm, int right_pwm) {
    if (left_pwm > 255) left_pwm = 255;
    if (left_pwm < -255) left_pwm = -255;
    if (right_pwm > 255) right_pwm = 255;
    if (right_pwm < -255) right_pwm = -255;

    // LEFT TRACK: IN1 (CH5), IN2 (CH6) - Both are hardware PWM
    if (left_pwm >= 0) {
        ledc_set_duty(LEDC_LOW_SPEED_MODE, CH_MOT_L_IN1, left_pwm);
        ledc_set_duty(LEDC_LOW_SPEED_MODE, CH_MOT_L_IN2, 0);
    } else {
        ledc_set_duty(LEDC_LOW_SPEED_MODE, CH_MOT_L_IN1, 0);
        ledc_set_duty(LEDC_LOW_SPEED_MODE, CH_MOT_L_IN2, -left_pwm);
    }

    // RIGHT TRACK: IN3 (CH7 PWM), IN4 (GPIO 19 Digital Level)
    if (right_pwm == 0) {
        ledc_set_duty(LEDC_LOW_SPEED_MODE, CH_MOT_R_IN3, 0);
        gpio_set_level(MOTOR_R_IN4, 0);
    } else if (right_pwm > 0) {
        ledc_set_duty(LEDC_LOW_SPEED_MODE, CH_MOT_R_IN3, right_pwm);
        gpio_set_level(MOTOR_R_IN4, 0);
    } else {
        int inverted_pwm = 255 - (-right_pwm);
        ledc_set_duty(LEDC_LOW_SPEED_MODE, CH_MOT_R_IN3, inverted_pwm);
        gpio_set_level(MOTOR_R_IN4, 1);
    }

    ledc_update_duty(LEDC_LOW_SPEED_MODE, CH_MOT_L_IN1);
    ledc_update_duty(LEDC_LOW_SPEED_MODE, CH_MOT_L_IN2);
    ledc_update_duty(LEDC_LOW_SPEED_MODE, CH_MOT_R_IN3);

    if (left_pwm != 0 || right_pwm != 0) {
        last_drive_cmd_time = esp_timer_get_time();
        motors_active = true;
    } else {
        motors_active = false;
    }
}

static void drive_stop(void) {
    set_motor_speeds(0, 0);
}

static void handle_drive_action(char *action_str) {
    if (action_str == NULL || strlen(action_str) == 0) return;

    if (strcmp(action_str, "STOP") == 0) {
        drive_stop();
        return;
    }

    int duty = current_drive_duty;

    char *colon_ptr = strchr(action_str, ':');
    if (colon_ptr != NULL) {
        *colon_ptr = '\0';
        int parsed_duty = atoi(colon_ptr + 1);
        if (parsed_duty > 0 && parsed_duty <= 255) {
            duty = parsed_duty;
            current_drive_duty = parsed_duty;
        }
    }

    char *cmd = action_str;

    ESP_LOGI(TAG, "CMD: %s | DUTY: %d", cmd, duty);

    if (strcmp(cmd, "FORWARD") == 0) {
        set_motor_speeds(duty, -duty);
    } else if (strcmp(cmd, "REVERSE") == 0) {
        set_motor_speeds(-duty, duty);
    } else if (strcmp(cmd, "SPIN_LEFT") == 0) {
        set_motor_speeds(duty, duty);
    } else if (strcmp(cmd, "SPIN_RIGHT") == 0) {
        set_motor_speeds(-duty, -duty);
    } else if (strcmp(cmd, "FWD_LEFT") == 0) {
        set_motor_speeds(duty, 0);
    } else if (strcmp(cmd, "FWD_RIGHT") == 0) {
        set_motor_speeds(0, -duty);
    } else if (strcmp(cmd, "REV_LEFT") == 0) {
        set_motor_speeds(-duty, 0);
    } else if (strcmp(cmd, "REV_RIGHT") == 0) {
        set_motor_speeds(0, duty);
    }
}

// ============================================================
// === Piecewise Smooth Linear Interpolation Functions ========
// ============================================================
static inline float lerp(float a, float b, float t) {
    return a + t * (b - a);
}

static float calc_smooth_claw_max(float arm_pct) {
    if (arm_pct <= 45.0f) return 180.0f;
    if (arm_pct <= 55.0f) return lerp(180.0f, 156.0f, (arm_pct - 45.0f) / (55.0f - 45.0f));
    if (arm_pct <= 60.0f) return lerp(156.0f, 151.0f, (arm_pct - 55.0f) / (60.0f - 55.0f));
    if (arm_pct <= 70.0f) return lerp(151.0f, 135.0f, (arm_pct - 60.0f) / (70.0f - 60.0f));
    if (arm_pct <= 80.0f) return lerp(135.0f, 120.0f, (arm_pct - 70.0f) / (80.0f - 70.0f));
    if (arm_pct <= 90.0f) return lerp(120.0f, 100.0f, (arm_pct - 80.0f) / (90.0f - 80.0f));
    if (arm_pct <= 100.0f) return lerp(100.0f, 90.0f, (arm_pct - 90.0f) / (100.0f - 90.0f));
    return 90.0f;
}

static float calc_smooth_cup_min(float arm_pct) {
    if (arm_pct <= 70.0f) return 0.0f;
    if (arm_pct <= 80.0f) return lerp(15.0f, 30.0f, (arm_pct - 70.0f) / 10.0f);
    if (arm_pct <= 90.0f) return lerp(30.0f, 55.0f, (arm_pct - 80.0f) / 10.0f);
    if (arm_pct <= 100.0f) return lerp(55.0f, 60.0f, (arm_pct - 90.0f) / 10.0f);
    return 60.0f;
}

static void calc_smooth_phone_intervals(float arm_pct, float *low_max, float *high_min) {
    if (arm_pct <= 70.0f) {
        *low_max = 180.0f;
        *high_min = 0.0f;
    } else if (arm_pct <= 80.0f) {
        float t = (arm_pct - 70.0f) / 10.0f;
        *low_max = lerp(115.0f, 100.0f, t);
        *high_min = 145.0f;
    } else if (arm_pct <= 90.0f) {
        float t = (arm_pct - 80.0f) / 10.0f;
        *low_max = lerp(100.0f, 95.0f, t);
        *high_min = 145.0f;
    } else {
        float t = (arm_pct - 90.0f) / 10.0f;
        if (t > 1.0f) t = 1.0f;
        *low_max = lerp(95.0f, 70.0f, t);
        *high_min = lerp(145.0f, 160.0f, t);
    }
}

static void govern_joint_limits_smooth(int64_t now_us) {
    float arm = current_arm_percent;

    // 1. Cup/Wrist Continuous Enforcement
    float min_cup = calc_smooth_cup_min(arm);
    servo_cup.target = (intent_cup < min_cup) ? min_cup : intent_cup;

    // 2. Claw Continuous Enforcement
    float max_claw = calc_smooth_claw_max(arm);
    servo_claw.target = (intent_claw > max_claw) ? max_claw : intent_claw;

    // 3. Phone / Cam Tilt Domain Protection & Delayed Auto-Restoration
    float low_max, high_min;
    calc_smooth_phone_intervals(arm, &low_max, &high_min);

    if (arm <= 70.0f) {
        if (cam_clearance_ready_time == 0) {
            cam_clearance_ready_time = now_us + 1000000;
        } else if (now_us >= cam_clearance_ready_time) {
            servo_cam.target = intent_cam;
        } else {
            servo_cam.target = intent_cam;
        }
    } else {
        cam_clearance_ready_time = 0;
        bool in_lower = (servo_cam.current <= low_max);
        bool in_upper = (servo_cam.current >= high_min);

        if (in_lower) {
            servo_cam.target = (intent_cam > low_max) ? low_max : intent_cam;
        } else if (in_upper) {
            servo_cam.target = (intent_cam < high_min) ? high_min : intent_cam;
        } else {
            servo_cam.target = intent_cam;
        }
    }
}

static void servo_smoothing_task(void *pvParameters) {
    while (1) {
        int64_t now = esp_timer_get_time();
        taskENTER_CRITICAL(&angle_mux);

        govern_joint_limits_smooth(now);

        if (fabsf(servo_cam.current - servo_cam.target) > 0.1f) {
            float delta = servo_cam.target - servo_cam.current;
            servo_cam.current += (fabsf(delta) <= servo_cam.max_step) ? delta : ((delta > 0) ? servo_cam.max_step : -servo_cam.max_step);
            apply_raw_servo(CH_SERVO_CAM, servo_cam.current);
        }

        if (fabsf(servo_arm_l.current - servo_arm_l.target) > 0.1f) {
            float delta = servo_arm_l.target - servo_arm_l.current;
            servo_arm_l.current += (fabsf(delta) <= servo_arm_l.max_step) ? delta : ((delta > 0) ? servo_arm_l.max_step : -servo_arm_l.max_step);
            apply_raw_servo(CH_SERVO_ARM_L, servo_arm_l.current);
        }

        if (fabsf(servo_arm_r.current - servo_arm_r.target) > 0.1f) {
            float delta = servo_arm_r.target - servo_arm_r.current;
            servo_arm_r.current += (fabsf(delta) <= servo_arm_r.max_step) ? delta : ((delta > 0) ? servo_arm_r.max_step : -servo_arm_r.max_step);
            apply_raw_servo(CH_SERVO_ARM_R, servo_arm_r.current);
        }

        if (fabsf(servo_cup.current - servo_cup.target) > 0.1f) {
            float delta = servo_cup.target - servo_cup.current;
            servo_cup.current += (fabsf(delta) <= servo_cup.max_step) ? delta : ((delta > 0) ? servo_cup.max_step : -servo_cup.max_step);
            apply_raw_servo(CH_SERVO_CUP, servo_cup.current);
        }

        if (fabsf(servo_claw.current - servo_claw.target) > 0.1f) {
            float delta = servo_claw.target - servo_claw.current;
            servo_claw.current += (fabsf(delta) <= servo_claw.max_step) ? delta : ((delta > 0) ? servo_claw.max_step : -servo_claw.max_step);
            apply_raw_servo(CH_SERVO_CLAW, servo_claw.current);
        }

        taskEXIT_CRITICAL(&angle_mux);
        vTaskDelay(pdMS_TO_TICKS(20));
    }
}

static bool check_and_apply_arm_percent(float target_pct) {
    if (target_pct < 0.0f)   target_pct = 0.0f;
    if (target_pct > 100.0f) target_pct = 100.0f;

    taskENTER_CRITICAL(&angle_mux);
    float cur_cam = servo_cam.current;

    // Hard ceiling: if phone is in the danger zone, arm CANNOT go above 70%
    if (cur_cam >= 115.0f && cur_cam <= 145.0f) {
        if (target_pct > 70.0f) {
            target_pct = 70.0f;
        }
    }

    // Corridor ceiling: if phone is in the interpolated forbidden band, clamp to 70%
    if (target_pct > 70.0f) {
        float low_max, high_min;
        calc_smooth_phone_intervals(target_pct, &low_max, &high_min);
        if (cur_cam > low_max && cur_cam < high_min) {
            target_pct = 70.0f;
        }
    }

    current_arm_percent = target_pct;
    float p = current_arm_percent / 100.0f;
    servo_arm_l.target = arm_cal.arm_l_down - p * (arm_cal.arm_l_down - arm_cal.arm_l_up);
    servo_arm_r.target = arm_cal.arm_r_down + p * (arm_cal.arm_r_up - arm_cal.arm_r_down);

    taskEXIT_CRITICAL(&angle_mux);
    return true;
}

static bool check_and_apply_cam_intent(float target_deg) {
    if (target_deg < 0.0f)   target_deg = 0.0f;
    if (target_deg > 180.0f) target_deg = 180.0f;

    taskENTER_CRITICAL(&angle_mux);
    float arm = current_arm_percent;
    float cur_cam = servo_cam.current;

    if (arm > 70.0f) {
        float low_max, high_min;
        calc_smooth_phone_intervals(arm, &low_max, &high_min);

        bool in_lower = (cur_cam <= low_max);
        if (in_lower) {
            if (target_deg > low_max) target_deg = low_max;
        } else {
            if (target_deg < high_min) target_deg = high_min;
        }
    }

    intent_cam = target_deg;
    servo_cam.target = target_deg;

    taskEXIT_CRITICAL(&angle_mux);
    return true;
}

static void init_actuators(void) {
    ledc_timer_config_t servo_t = {
        .speed_mode       = LEDC_LOW_SPEED_MODE,
        .timer_num        = SERVO_TIMER,
        .duty_resolution  = SERVO_DUTY_RES,
        .freq_hz          = SERVO_FREQ_HZ,
        .clk_cfg          = LEDC_AUTO_CLK
    };
    ESP_ERROR_CHECK(ledc_timer_config(&servo_t));

    ledc_timer_config_t motor_t = {
        .speed_mode       = LEDC_LOW_SPEED_MODE,
        .timer_num        = MOTOR_TIMER,
        .duty_resolution  = MOTOR_DUTY_RES,
        .freq_hz          = MOTOR_FREQ_HZ,
        .clk_cfg          = LEDC_AUTO_CLK
    };
    ESP_ERROR_CHECK(ledc_timer_config(&motor_t));

    float start_arm_l = arm_cal.arm_l_down - 0.40f * (arm_cal.arm_l_down - arm_cal.arm_l_up);
    float start_arm_r = arm_cal.arm_r_down + 0.40f * (arm_cal.arm_r_up - arm_cal.arm_r_down);

    // Initial hardware duty configured explicitly to 0.0f (opposite of 180 deg)
    ledc_channel_config_t servos[] = {
        { .gpio_num = CAM_SERVO_PIN,   .channel = CH_SERVO_CAM,   .duty = angle_to_ticks(0.0f) },
        { .gpio_num = ARM_L_SERVO_PIN, .channel = CH_SERVO_ARM_L, .duty = angle_to_ticks(start_arm_l) },
        { .gpio_num = ARM_R_SERVO_PIN, .channel = CH_SERVO_ARM_R, .duty = angle_to_ticks(start_arm_r) },
        { .gpio_num = CUP_SERVO_PIN,   .channel = CH_SERVO_CUP,   .duty = angle_to_ticks(90.0f) },
        { .gpio_num = CLAW_SERVO_PIN,  .channel = CH_SERVO_CLAW,  .duty = angle_to_ticks(90.0f) },
    };

    for (int i = 0; i < 5; i++) {
        servos[i].speed_mode = LEDC_LOW_SPEED_MODE;
        servos[i].timer_sel  = SERVO_TIMER;
        servos[i].intr_type  = LEDC_INTR_DISABLE;
        servos[i].hpoint     = 0;
        ESP_ERROR_CHECK(ledc_channel_config(&servos[i]));
    }

    ledc_channel_config_t motors[] = {
        { .gpio_num = MOTOR_L_IN1, .channel = CH_MOT_L_IN1 },
        { .gpio_num = MOTOR_L_IN2, .channel = CH_MOT_L_IN2 },
        { .gpio_num = MOTOR_R_IN3, .channel = CH_MOT_R_IN3 }
    };
    for (int i = 0; i < 3; i++) {
        motors[i].speed_mode = LEDC_LOW_SPEED_MODE;
        motors[i].timer_sel  = MOTOR_TIMER;
        motors[i].intr_type  = LEDC_INTR_DISABLE;
        motors[i].duty       = 0;
        motors[i].hpoint     = 0;
        ESP_ERROR_CHECK(ledc_channel_config(&motors[i]));
    }

    gpio_config_t io_conf = {
        .pin_bit_mask = (1ULL << MOTOR_R_IN4),
        .mode = GPIO_MODE_OUTPUT,
        .pull_down_en = 0,
        .pull_up_en = 0,
        .intr_type = GPIO_INTR_DISABLE
    };
    gpio_config(&io_conf);
    gpio_set_level(MOTOR_R_IN4, 0);

    // Initial raw PWM output explicitly applied at 0.0f
    apply_raw_servo(CH_SERVO_CAM, 0.0f);
    apply_raw_servo(CH_SERVO_ARM_L, start_arm_l);
    apply_raw_servo(CH_SERVO_ARM_R, start_arm_r);
    apply_raw_servo(CH_SERVO_CUP, 90.0f);
    apply_raw_servo(CH_SERVO_CLAW, 90.0f);
}

// ----------------------------------------------------
// DRIVE CALLBACK: /bulldozer/drive_cmd
// ----------------------------------------------------
void drive_callback(const void * msgin) {
    const std_msgs__msg__String * msg = (const std_msgs__msg__String *)msgin;
    if (!msg || !msg->data.data) return;

    char buf[32];
    strncpy(buf, msg->data.data, sizeof(buf) - 1);
    buf[sizeof(buf) - 1] = '\0';

    handle_drive_action(buf);
}

// ----------------------------------------------------
// ARM / MANIPULATOR CALLBACK: /bulldozer/arm_cmd
// ----------------------------------------------------
void arm_callback(const void * msgin) {
    const std_msgs__msg__String * msg = (const std_msgs__msg__String *)msgin;
    if (!msg || !msg->data.data) return;
    const char *cmd = msg->data.data;

    if (strcmp(cmd, "ARM_UP") == 0) {
        check_and_apply_arm_percent(current_arm_percent + 2.25f);
    } else if (strcmp(cmd, "ARM_DOWN") == 0) {
        check_and_apply_arm_percent(current_arm_percent - 2.25f);
    } else if (strcmp(cmd, "CUP_UP") == 0) {
        taskENTER_CRITICAL(&angle_mux);
        intent_cup = fmaxf(0.0f, intent_cup - 3.5f);
        taskEXIT_CRITICAL(&angle_mux);
    } else if (strcmp(cmd, "CUP_DOWN") == 0) {
        taskENTER_CRITICAL(&angle_mux);
        intent_cup = fminf(180.0f, intent_cup + 3.5f);
        taskEXIT_CRITICAL(&angle_mux);
    } else if (strcmp(cmd, "CLAW_CLOSE") == 0) {
        taskENTER_CRITICAL(&angle_mux);
        intent_claw = fminf(180.0f, intent_claw + 3.5f);
        taskEXIT_CRITICAL(&angle_mux);
    } else if (strcmp(cmd, "CLAW_OPEN") == 0) {
        taskENTER_CRITICAL(&angle_mux);
        intent_claw = fmaxf(0.0f, intent_claw - 3.5f);
        taskEXIT_CRITICAL(&angle_mux);
    } else if (strcmp(cmd, "CAM_UP") == 0) {
        check_and_apply_cam_intent(intent_cam + 8.0f);
    } else if (strcmp(cmd, "CAM_DOWN") == 0) {
        check_and_apply_cam_intent(intent_cam - 8.0f);
    }
}

static void wifi_event_handler(void* arg, esp_event_base_t event_base, int32_t event_id, void* event_data) {
    if (event_base == WIFI_EVENT && event_id == WIFI_EVENT_STA_START) {
        esp_wifi_connect();
    } else if (event_base == WIFI_EVENT && event_id == WIFI_EVENT_STA_DISCONNECTED) {
        xEventGroupClearBits(wifi_event_group, WIFI_CONNECTED_BIT);
        esp_wifi_connect();
    } else if (event_base == IP_EVENT && event_id == IP_EVENT_STA_GOT_IP) {
        xEventGroupSetBits(wifi_event_group, WIFI_CONNECTED_BIT);
    }
}

static void wifi_init_sta(void) {
    wifi_event_group = xEventGroupCreate();
    ESP_ERROR_CHECK(esp_netif_init());
    ESP_ERROR_CHECK(esp_event_loop_create_default());
    esp_netif_create_default_wifi_sta();

    wifi_init_config_t cfg = WIFI_INIT_CONFIG_DEFAULT();
    ESP_ERROR_CHECK(esp_wifi_init(&cfg));

    ESP_ERROR_CHECK(esp_event_handler_instance_register(WIFI_EVENT, ESP_EVENT_ANY_ID, &wifi_event_handler, NULL, NULL));
    ESP_ERROR_CHECK(esp_event_handler_instance_register(IP_EVENT, IP_EVENT_STA_GOT_IP, &wifi_event_handler, NULL, NULL));

    wifi_config_t wifi_config = {
        .sta = {
            .ssid = TARGET_SSID,
            .password = TARGET_PASS,
            .threshold.authmode = WIFI_AUTH_WPA2_PSK,
        },
    };
    ESP_ERROR_CHECK(esp_wifi_set_mode(WIFI_MODE_STA));
    ESP_ERROR_CHECK(esp_wifi_set_config(WIFI_IF_STA, &wifi_config));
    ESP_ERROR_CHECK(esp_wifi_start());
    esp_wifi_set_max_tx_power(78);
    ESP_ERROR_CHECK(esp_wifi_set_ps(WIFI_PS_NONE));

    ESP_LOGI(TAG, "Connecting to Wi-Fi: %s...", TARGET_SSID);
    xEventGroupWaitBits(wifi_event_group, WIFI_CONNECTED_BIT, pdFALSE, pdTRUE, portMAX_DELAY);
    ESP_LOGI(TAG, "Wi-Fi Connected successfully.");
}

void safety_watchdog_task(void *pvParameters) {
    while (1) {
        if (motors_active && (esp_timer_get_time() - last_drive_cmd_time > DRIVE_TIMEOUT_US)) {
            drive_stop();
        }
        vTaskDelay(pdMS_TO_TICKS(10));
    }
}
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
void app_main(void) {
    esp_err_t ret = nvs_flash_init();
    if (ret == ESP_ERR_NVS_NO_FREE_PAGES || ret == ESP_ERR_NVS_NEW_VERSION_FOUND) {
        ESP_ERROR_CHECK(nvs_flash_erase());
        ret = nvs_flash_init();
    }
    ESP_ERROR_CHECK(ret);

    init_actuators();
    wifi_init_sta();

    xTaskCreatePinnedToCore(servo_smoothing_task, "servo_slew", 2048, NULL, 6, NULL, 1);
    xTaskCreatePinnedToCore(safety_watchdog_task, "watchdog", 2048, NULL, 10, NULL, 1);
    xTaskCreatePinnedToCore(micro_ros_task, "uros_task", 4096 * 4, NULL, 5, NULL, 0);
}

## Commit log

2026-09-15 Initial commit: clean project setup
    [FlipperCar_Electronics_v1_legacy.kicad_sch, FlipperCar_Electronics_v2.kicad_sch, flipper_car.urdf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]
2026-09-16 HIL setup done
    [Part Studio 1 - 02_Chassis_Base.stl, Part Studio 1 - 03_Arm_Base_Mount_Left.stl, Part Studio 1 - 04_Arm_Base_Mount_Right.stl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]
2026-09-20 code for esp32 server
2026-09-20 esp32 connects to phone hotspot
2026-09-24 documentation updates
    [FlipperCar_Electronics_v1_legacy.kicad_sch, FlipperCar_Electronics_v2.kicad_sch, Schematic.kicad_sch]
2026-10-03 web debugging dashboard & servo collision angle discovery helper added.
    [bulldozer_firmware.c]
2026-10-03 hardcoded servos angles collision prevention restrictions added
    [bulldozer_firmware.c]
2026-10-04 Archive working standalone web teleop firmware with calibrated collision limits
    [bulldozer_firmware.c]
2026-10-05 finished cameras flow and UI
